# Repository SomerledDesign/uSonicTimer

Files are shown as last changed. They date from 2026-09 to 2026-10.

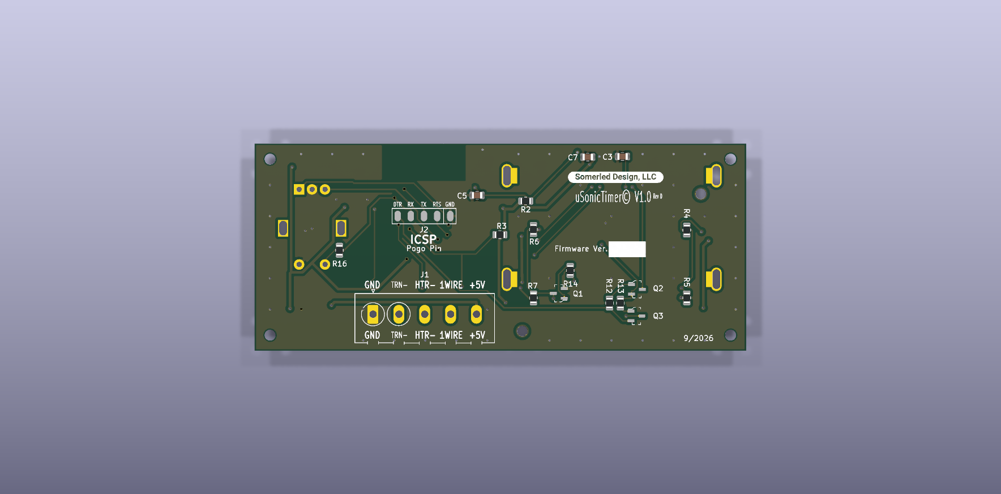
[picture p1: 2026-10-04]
hardware/uSonicTimer_1d/Renders/uSonicTimer1d_bottom.png

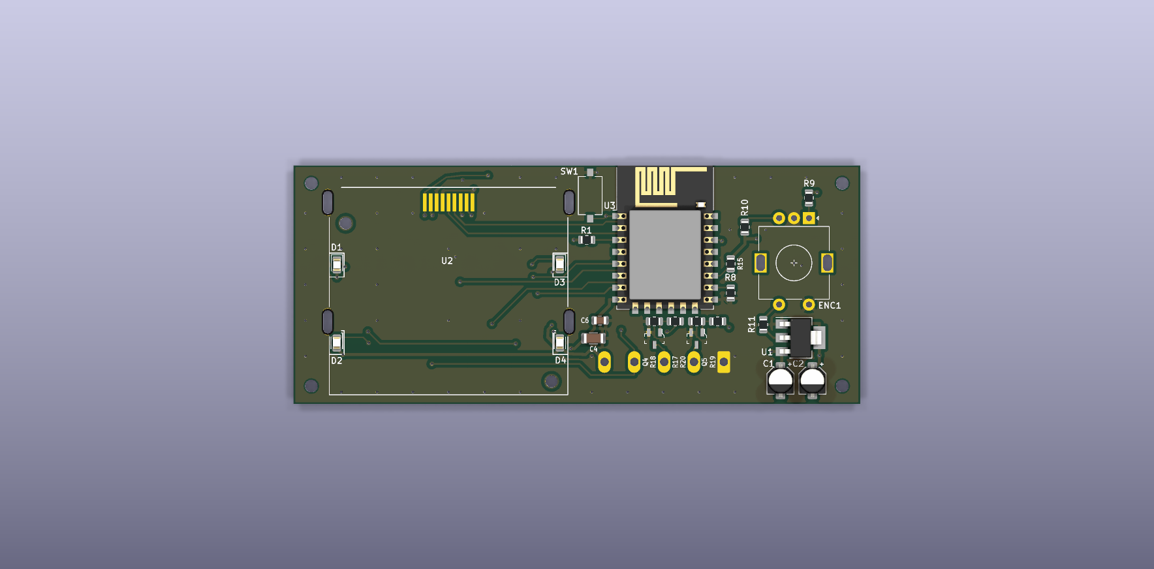
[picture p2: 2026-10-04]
hardware/uSonicTimer_1d/Renders/uSonicTimer1d_top.png

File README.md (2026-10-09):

# uSonicTimer

Firmware for a timer and heater controller I added to a cheap ultrasonic cleaner. It runs on an
**ESP8266 (ESP-12E module)**. A **Nokia 5110 (PCD8544, 84x48) LCD** shows a menu that you drive with a
**rotary encoder and its push button**. A **DS18B20 1-Wire temperature sensor** measures the bowl
temperature. Two outputs drive **solid-state relays** that switch the 110 VAC bowl **heater** and the
ultrasonic **cleaner**. The set temperature, timer preset, display unit (°F/°C), LCD contrast and
backlight brightness are saved in (emulated) EEPROM, so they survive a power cycle.

The menu approach comes from the [educ8s.tv](https://www.youtube.com/@Educ8s)
[menu tutorial](https://youtu.be/ak5TsUFhyf8?si=9JEMm8WbRyF4dVVC).

> Status: in active development (v0.6.1, PCB Rev D).

## What it does

1. On power-up it loads the settings from EEPROM. If a value is unset or out of range it uses a
   default: 72 °F, 10 min, °F, contrast 52 (raw 128), backlight level 10. It then initialises the
   LCD, the DS18B20, the encoder and the button.
2. It shows the main menu. You pick an item and a long press opens it.
3. **Start** runs the cleaner for the set time and regulates the heater (the control logic always
   works in °F, with tenths; the screens show whole degrees in the chosen unit):
   - **Heating:** below set − 10 °F the **heater is ON**, the **cleaner is OFF** and the countdown
     **holds**. The screen shows the bowl temperature in big digits and "Heating to 120°F"; the
     rule under the digits fills as the bowl warms from where heating started to set − 8 °F.
   - **Cleaning:** at set − 8 °F or above (2 °F hysteresis) the **heater is OFF**, the **cleaner is
     ON** and the countdown runs. The screen shows the time left as big `MM:SS` with a blinking
     colon, the rule under it fills with the run's progress, and "Now 118 Set 120°F" underneath.
     If the bowl drops below set − 10 °F the heater comes back on and the countdown holds again.
     Only cleaning time counts towards the run.
   - **No sensor:** heater locked off, cleaner on, the countdown runs; the time screen shows
     "NO SENSOR" instead of the temperatures.
   - When the time is up both outputs switch off and a big **DONE** stays on screen until you turn
     or press; then the menu returns. A long press during the run aborts it (both outputs off).

## Menu tree

In the menus, rotating the encoder moves the reverse-video highlight (lists show 4 rows under the
title bar and scroll; small arrows mark more items), a **long press** (> 1 s) enters the
highlighted item, and a **short press** toggles the LCD backlight between off and the level set in
**Set backlight**. The backlight is on at power-up.
Its state is kept while you are in a page, because short presses inside the pages move the cursor
or confirm instead. After 5 minutes without input in the menu the backlight dims to about 20 %; the
first turn or press then only wakes it. Every button press is handled exactly once, so a press never
carries over into the next page.

**Encoder test:** hold the button while powering up (or pressing reset) to get a test screen with the
live A/B levels, the detent count and how often each input has changed; long press returns to the
menu. Both edge counts should rise together while turning. `ENCODER_STEPS_PER_DETENT` in
`src/main.cpp` is 2 for an encoder whose detents rest at both 00 and 11, 4 for one that always rests
at the same state.

The backlight also shows the status (it swings between the set brightness and about 30 % of it, so
the screen stays readable):

- **Steady**: normal operation (menu, cleaning).
- **Flashing** (1 Hz): heating up.
- **Pulsing** (slow): the timer has finished; stops at the next turn or press.
- **Double-blink** every 2 s: no temperature sensor during a run (heater locked off, cleaner runs).

Pulsing and double-blink also show when the backlight has been toggled off or set to level 0 (then
at level 5); heating and cleaning then stay dark.

```
Main menu "uSonicTimer"      (shows the set temperature and time underneath)
├── Start             heating screen (big temperature) / timer screen (big MM:SS) / DONE, as above
│                     long press = abort (both outputs off)
└── Settings...
    ├── Set temp      "ddd°F" (3 digits) or "dd°C" (2 digits), cursor digit in reverse video
    │                 rotate = change digit (0–9, wraps); press = next digit ("Press = next"),
    │                 press on the last digit = save and return ("Press = save");
    │                 long press = save from any digit (clamped 60–180 °F / 16–82 °C, stored in °F)
    ├── Set time      "<n> min"; rotate = preset 3, 8, 10, 15, 20, 30, 60 min (wraps)
    │                 press = save and return
    ├── Set units     "°F Fahrenheit" / "°C Celsius"; rotate = toggle, press = save and return
    ├── Set backlight "Off" / "Level 1"…"Level 10" with a bar; rotate = level (previewed live)
    │                 press = save, switch the backlight on and return
    ├── Set contrast  20–100 with a bar (mapped onto the usable raw 80–200); clockwise = higher,
    │                 accelerated (detents < 40 ms apart = 5 steps, < 90 ms = 2, else 1),
    │                 applied live; press = save and return
    └── Exit          back to the main menu
```

Settings are saved to EEPROM when you leave their page: set temperature `0x00` (°F), time `0x08`,
contrast `0x10` (raw 80–200, so the 0.5.0 value carries over), backlight level `0x18`, units `0x20`
(0 = °F, 1 = °C) and a layout id `0x28` (0x60) that marks EEPROM written by 0.6.0 or later. Every
value is range-checked on load; a backlight level of 0 is only accepted together with that id.

## Hardware (PCB rev 1d) pin map

The KiCad design files for this board are in [`hardware/uSonicTimer_1d/`](hardware/uSonicTimer_1d/).

| Signal | Arduino pin | ESP8266 GPIO | ESP-12E pin | Notes |
|---|---|---|---|---|
| LCD SCLK | D5 | GPIO14 | 5 | software SPI clock |
| LCD DIN | D7 | GPIO13 | 7 | software SPI data |
| LCD D/C | D10 | GPIO1 (TX) | 22 | shared with UART TX |
| LCD CS | D4 | GPIO2 | 17 | 10K pull-up |
| LCD RST | – | – | – | not connected (`U8X8_PIN_NONE`) |
| LCD backlight | D8 | GPIO15 | 16 | via Q1, 10K pull-down |
| Encoder CLK (A) | D0 | GPIO16 | 4 | 4K7 pull-up (R9), polled (no interrupt on GPIO16) |
| Encoder DT (B) | D6 | GPIO12 | 6 | 4K7 pull-up (R10), polled |
| Encoder SW | D9 | GPIO3 (RX) | 21 | shared with UART RX |
| Heater SSR | D2 | GPIO4 | 19 | HIGH = ON |
| Cleaner SSR | D1 | GPIO5 | 20 | HIGH = ON |
| DS18B20 1-Wire | D3 | GPIO0 | 18 | 4K7 pull-up; also ~PROGRAM strap |

On rev 1d, NPN transistors switch the heater and cleaner SSRs low-side. The logic is the same as
before: GPIO HIGH = ON.

The programming header is a set of 5 pogo pads: 1 GND, 2 RTS, 3 TX, 4 RX, 5 DTR. RTS and DTR
drive the auto-reset/boot circuit (Q2/Q3).

Because the UART pins are also used for the LCD D/C line and the encoder switch, serial output
from the `debug` build shares those lines with the hardware.

## Building and flashing (PlatformIO)

The project uses the `espressif8266` platform, board `esp12e` and the Arduino framework. It needs
these libraries, which PlatformIO fetches automatically from `platformio.ini`:
`olikraus/U8g2`, `lennarthennigs/ESP Rotary`, `lennarthennigs/Button2`, `paulstoffregen/OneWire`
and `milesburton/DallasTemperature`. `EEPROM` and `Ticker` come with the ESP8266 core.

```sh
pio run -e release                  # build the release firmware
pio run -e release -t upload        # flash it over the programming header
pio device monitor -b 115200        # serial monitor (debug output)
```

- `release` is the default environment (`default_envs = release`); it builds without the debug
  output.
- `debug` (`pio run -e debug`) adds `-Og -ggdb -g3 -D DEBUG -D WITH_GDB`. It enables the
  serial `debug()`/`debugln()` output at 115200 baud.
- `platformio.ini` puts `build_dir` and `libdeps_dir` under
  `$HOME/Library/Caches/PlatformIO/uSonicTimer/`, which keeps build output out of Dropbox. On a
  non-macOS machine, change these paths or remove them to use the default `.pio/` folder.

## Versioning

Firmware versions are a semantic version plus a build number, shown as **`0.6.1 (73)`** (current).

- Bump PATCH for fixes and MINOR for features; 1.0.0 is the first version installed and in service.
- The build number goes up by 1 for every build flashed for testing and never resets.
- `FW_VERSION`, `FW_BUILD` and `HW_REV` at the top of `src/main.cpp` set it. The startup screen
  shows `uSonicTimer` / `v0.6.1 (73)` / `PCB Rev D` for 1.5 s at power-up. Releases are tagged
  `vMAJOR.MINOR.PATCH` in git.

History:

- **0.6.1 (73)**: new big-digit font: blocky, squared-off 7-segment-style characters (4–5 px
  strokes, no diagonals, stepped slashed zero, colon of two 4x4 blocks) drawn from box lists in
  `include/bigfont.h`, closer to the reference clock than the scaled 5x7 font. Encoder
  acceleration in Set contrast (5 / 2 / 1 steps per detent for detents
  < 40 ms / < 90 ms / slower apart). A press saves in every settings page ("Press = save"); in Set
  temp a press moves to the next digit and saves on the last one, long press still saves anywhere.
  Detents still queued when a page closes no longer move the menu highlight.
- 0.6.0 (72): big-digit run screens in the style of a Nokia 5110 clock (Adafruit 5x7 digits
  scaled to 15x28 px, a rule that doubles as a progress bar, one line of small text): heating
  screen with the bowl temperature, timer screen with blinking colon, DONE screen. The countdown
  holds while heating (heater below set − 10 °F, cleaning resumes at set − 8 °F). Main menu is now
  Start / Settings...; Settings has Set temp, Set time, Set units (°F/°C, new), Set backlight
  (0 = off, new), Set contrast (shown as 20–100) and Exit, with title bars.
- 0.5.0 (71), `2d4bacc`: version defines, startup screen, versioning notes.
- Build 70, `a255348`: polled quadrature decoder (replaces ESPRotary) and the encoder test screen.
- Build 69, `44c0249`: backlight as status indicator and the Backlight brightness menu (`90cbc71`).

## Setup and usage

1. Wire the board as in the pin map, or use the rev 1d PCB. Put the DS18B20 on the bowl and
   connect the heater and cleaner through the SSRs.
2. Build and flash as above, then power up. The main menu appears.
3. Open **Settings...** and use **Set temp** to choose the target bowl temperature, **Set time**
   to choose the run time, **Set units** for °F or °C, and **Set backlight** / **Set contrast** for
   the LCD if needed. Each setting is saved when you leave its page.
4. Highlight **Start** and long-press. The display shows the bowl temperature while it heats, then
   the time left while it cleans; the heater and cleaner are controlled automatically.
5. Long-press at any time to stop. Both outputs switch off. When the time is up, DONE shows until
   you turn or press.

## Repository layout

- `src/main.cpp`: the firmware (setup, menus, pages, run control, EEPROM, backlight).
- `src/screens.cpp`, `include/screens.h`: drawing for the run screens, menus and settings pages.
- `include/ust_logic.h`: run-control hysteresis, °F/°C, contrast and progress helpers (no Arduino
  dependencies).
- `include/bigfont.h`: the big-digit font (blocky 15x28 characters as box lists, slashed zero).
- `tools/host/`: host-side test of `ust_logic.h` and a screen preview that runs the real drawing
  code against the U8g2 C library on a PC (`tools/host/build.sh`, writes PNGs to
  `tools/host/out/`).
- `src/sketch.md`: design notes and the original specification.
- `include/`: also the old splash/footer glyph bitmaps.
- `handoff.md`: latest status and decisions.
- `hardware/uSonicTimer_1d/`: KiCad project for the rev 1d controller board (schematic, PCB,
  project symbol/footprint libraries, Gerbers, interactive BOM and renders).
- `extras/` (git-ignored): local reference material. This includes third-party menu/encoder demo
  code, links to the KiCad hardware projects and links to the datasheets, which are archived
  centrally.

## License

uSonicTimer uses two licences, one for the code and one for the hardware:

- **Firmware and code** (`src/`, `include/`, `platformio.ini` and the rest of the software) are
  under the GNU General Public License, version 3 or later. See [`LICENSE`](LICENSE).
  SPDX-License-Identifier: GPL-3.0-or-later
- **Hardware design files** (everything under [`hardware/`](hardware/): the KiCad schematic,
  PCB, libraries and related fabrication files for the controller board, and the same files
  wherever else they are published for this project) are under the CERN Open Hardware Licence
  Version 2, Strongly Reciprocal. See [`LICENSE-HARDWARE`](LICENSE-HARDWARE).
  SPDX-License-Identifier: CERN-OHL-S-2.0

Both licences come with no warranty. This controller switches 110 VAC mains through solid-state
relays; build and use it at your own risk.

Copyright © 2024 Somerled Design, LLC.

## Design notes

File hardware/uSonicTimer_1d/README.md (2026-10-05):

# uSonicTimer controller board, rev 1d

KiCad 10 project for the uSonicTimer controller PCB (schematic rev D). The firmware
pin map in the top-level [`README`](../../README.md) matches this board.

| Path | Contents |
|---|---|
| `uSonicTimer1d.kicad_pro` | KiCad project (open this) |
| `uSonicTimer1d.kicad_sch` | Schematic |
| `uSonicTimer1d.kicad_pcb` | PCB layout |
| `uSonicTimer1d.kicad_dru` | Custom design rules |
| `uSonicTimer1d.kicad_sym`, `sym-lib-table` | Project symbol library |
| `uSonicTimer1d.pretty/`, `fp-lib-table` | Project footprint library |
| `3dmodels/` | Project 3D models folder (currently only a README: sources, licences and excluded models) |
| `Gerber/` | Fabrication outputs: Gerbers, drill files, job file and `uSonicTimer1d_revD_gerbers.zip` for ordering |
| `bom/ibom.html` | Interactive BOM (open in a browser) |
| `Renders/` | Top and bottom board renders |
| `[TODO]/` | Changes planned for the next board revision |

The library tables use `${KIPRJMOD}`, so the project opens from any location. Every
symbol and footprint is in the project libraries. Every 3D model comes from the stock
KiCad 10 3D library, so nothing is needed outside this folder and a standard KiCad 10
install. The encoder (ENC1) and the screw terminal (J1) have no 3D body: their
third-party models can't be redistributed. Sources and licences are listed in
[`3dmodels/README.md`](3dmodels/README.md).

Licensed under the CERN Open Hardware Licence Version 2, Strongly Reciprocal. See
[`LICENSE-HARDWARE`](../../LICENSE-HARDWARE).
SPDX-License-Identifier: CERN-OHL-S-2.0

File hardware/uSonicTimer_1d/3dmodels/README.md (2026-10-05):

# 3D models: uSonicTimer rev 1d

This folder holds the project-local 3D models. Footprints reference them as
`${KIPRJMOD}/3dmodels/<file>.step`. The other bodies on the board (resistors,
capacitors, LEDs, Q1-Q5, SW1, U1, U3 and so on) come from the stock KiCad 10 3D library
(`${KICAD10_3DMODEL_DIR}`, installed with KiCad). That library is licensed under CC-BY-SA 4.0
with the KiCad library exception, so it can be used in any design.

## Our own models (in this folder)

Drawn by Somerled Design (Kevin Murphy) with Mildrew (Grok Bot).
Licence: CERN-OHL-S-2.0 (same as the rest of this hardware; see `LICENSE-HARDWARE` in the repository root).

Each model comes as a multi-colour STEP (one coloured solid per part) and a coloured VRML
(`.wrl`, KiCad scale 1 unit = 2.54 mm). Both are generated by `build_3dmodels.py` in this folder (CadQuery; run `python build_3dmodels.py`), which is the editable source. The model origin is
the footprint origin, so every footprint uses offset 0 0 0, scale 1 and rotation 0 0 0.
Dimensions are taken from the datasheets listed. Where a datasheet gives no value, the table
says what was used instead.

| File | Used by | Datasheet (dimension source) |
|---|---|---|
| `RotaryEncoder_Alps_EC11E_Switch_Vertical_H20mm.step` / `.wrl` | ENC1, footprint `RotaryEncoder_Alps_EC11E-Switch_Vertical_H20mm` | Alps Alpine EC11E series catalogue, Drawing No.2/No.3 (with push switch): https://tech.alpsalpine.com/cms.media/product_catalog_ec_01_ec11e_en_611f078659.pdf |
| `TerminalBlock_Metaltex_BR4_1x05_P5.00mm_Horizontal.step` / `.wrl` | J1, footprint `ScrewContact_ALLELEC_2,5_5-G-5,00_1x05_P5.00mm_Horizontal_copy_copy` | Metaltex BR4 terminal block (BR402V + BR403V, 5.0 mm pitch): https://metaltex.com.br/cdn/shop/files/br4.pdf |
| `LCD_Nokia_5110-3310_bare_frame.step` / `.wrl` | U2, footprint `Nokia_5110-3310_LCD_uSonic1d` | Goldentek GG0804A1FSN6G (PCD8544 84x48 glass) spec, section 12 "Outline dimension": https://thecustomizewindows.cachefly.net/wp-content/uploads/2017/06/Nokia-5110-datasheet.pdf, plus Kevin's frame measurements (`measurements.md`, `extras/bezel/README_bezel.md`) |

### ENC1: Alps EC11E with push switch, vertical, 20 mm shaft

From the datasheet:
- Body 12 x 11.7 mm. Shaft axis 7.5 mm from pins A/C/B and 7 mm from switch pins D/E.
  A-C-B pitch 2.5 mm, D-E 5 mm.
- Mounting surface 4.5 mm above the PCB. Overall height 24.5 mm (20 mm from the mounting surface).
- Bushing length 7 mm.
- Shaft Ø6 mm, flat 4.5 mm across over the top 10 mm.
- Pins and mounting tabs 3.5 mm below the PCB.

Not given in the datasheet, so assumed:
- Bushing Ø7 mm.
- Split between the black housing (0-3.8 mm) and the silver metal frame (2.0-4.5 mm).
- Pin cross-section 0.3 x 0.8 mm and tab size 2.0 x 0.5 mm.
- Tip chamfer 0.5 mm (the drawing says C1).
- Direction of the shaft flat.

The mounting tabs are drawn at the footprint's MP pads, which are 11.2 mm apart. The datasheet
hole pattern gives 12.5 ±0.05 mm.

### J1: 5-way 5.0 mm terminal block (Metaltex BR4)

From the datasheet:
- 5.0 mm per way; body 25 mm long (2.5 mm overhang past the end pins).
- 10.2 mm deep. Pin 5 mm from the wire-entry face, which faces the footprint's +Y side, where
  the silkscreen entry marks are.
- 14.2 mm high. Pins 0.8 mm square, 3.5 mm long.
- M2.5 zinc-plated screws; green PA66 housing.
- Drawn as one 2-way plus one 3-way block (BR402V + BR403V), with the joint between pins 2 and 3.

Not dimensioned in the drawing, so read off it:
- Shoulder height 9 mm and top width about 6.2 mm.
- Wire-entry opening 3.2 x 5.8 mm.
- Screw head Ø4 mm, recessed 1.8 mm.

The 0.6 mm interlock step is not modelled.

The board previously used Metaltex `BR1102V` + `BR1103V` models scaled by 0.5. The BR11 series
(https://metaltex.com.br/cdn/shop/files/br11.pdf) has a **9.5 mm** pitch, so it does not fit this
5.00 mm footprint. BR4 is Metaltex's 5.0 mm modular equivalent. The footprint's own fab outline
is a generic 27 x 9.5 mm box, so the model is 1 mm deeper at the back than that outline.

### U2: bare Nokia 5110/3310 LCD in its metal frame

The footprint is for the bare LCD with its metal frame (elastomer contacts on 9 SMD pads, four
frame tabs in slots, backlight LEDs D1-D4 on this board), not for the red/blue breakout board.
So the model has no breakout PCB or header.

From the datasheet:
- Glass 38.36 x 33 mm, with a 6.4 mm contact ledge (upper plate 26.6 mm).
- Glass stack 2.0 mm thick (maximum).
- Viewing area 34.96 x 23.4 mm, 1.7 mm from the glass edges.

From Kevin's measurements:
- Frame opening 36.23 x 25.85 mm.
- Frame borders: 1.6 mm left and right, 6.77 mm on the contact side, 1.45 mm on the other side.
- So the frame outline is 39.43 x 34.07 mm. Its contact-side edge is on the footprint's y = 0
  silk line, as in the bezel notes.

Assumed or taken from the footprint:
- Frame top 4.4 mm above the PCB. This is the 6 mm module thickness (Hobby Components spec)
  minus the breakout PCB; no datasheet gives it.
- Light guide 2.1 mm, with LED pockets at the silkscreen notches.
- Locating pegs in the two Ø2 mm holes.
- Tabs 0.4 x 2.8 mm at the slot centres.
- Elastomer strip 10 x 3 mm.

## Third-party models removed from the board and the project footprints (2026-10-04)

| Part | Footprint | Model referenced before | Source and licence | Decision |
|---|---|---|---|---|
| Q1-Q5 | `SOT-23-3` | `/Users/.../KiCad/lib/3dmodels/km3dpacks/User Library-SOT23-3.step` (absolute path) | Downloaded by Kevin from Dassault's 3D ContentCentral (3dcontentcentral.com); the "User Library-…" name is its export naming. SolidWorks 2022 STEP, 2023-02-13. User-uploaded under Dassault's terms. | **Not committed** (no redistribution licence). Replaced by the stock `Package_TO_SOT_SMD.3dshapes/SOT-23-3.step` (same package, same pad layout). |
| ENC1 | `RotaryEncoder_Alps_EC11E-Switch_Vertical_H20mm` | `${MYSPECLMOD}/EC11 Rotary Encoder Dode Switch-15mm .STEP` (offset 7.5 -2.5 0.1, rot 0 0 90) | GrabCAD model "EC11 Rotary Encoder Dode Switch-15mm" by user *xindela* (SolidWorks 2016, 2021-10-20). GrabCAD terms allow only non-commercial, internal use, under a non-sublicensable licence. | **Not committed** (can't be relicensed or redistributed). Replaced by our own `RotaryEncoder_Alps_EC11E_Switch_Vertical_H20mm.step` (see above). |
| ENC1 (hidden) | same | `${MYSPECLMOD}/User Library-EC11B15244.STEP` | Downloaded by Kevin from 3D ContentCentral ("User Library-…" export naming). User-uploaded under Dassault's terms. File is no longer on Kevin's machines. | Removed |
| ENC1 (hidden) | same | `${KICAD6_3DMODEL_DIR}/Rotary_Encoder.3dshapes/...EC11E-Switch_Vertical_H20mm.wrl` | KiCad stock path, but KiCad 10 ships no such model. | Removed (dangling) |
| SW1 | `SW_Tactile_SPST_NO_Straight_CK_PTS636Sx25SMTRLFS` | `${MYSPECLMOD}/g73-6x3-5-mm-smd-button-1/...PTS636Sx25SMTRLFS.STEP` | File isn't on Kevin's machines. Probably 3D ContentCentral like the others; the folder name also looks like a GrabCAD download ("g73-6x3-5-mm-smd-button-1"). | Removed. The stock KiCad model for this exact C&K part was already on the footprint (hidden); it is now shown. |
| J1 | `ScrewContact_ALLELEC_2,5_5-G-5,00_1x05_P5.00mm_Horizontal_copy_copy` | `${MYSPECLMOD}/pcb-terminal-blocks-1/BR1102V.stp` and `BR1103V.stp` (scaled 0.5) | Files aren't on Kevin's machines. Probably 3D ContentCentral like the others; the folder name also looks like a GrabCAD download ("pcb-terminal-blocks-1"). | Removed. Replaced by our own `TerminalBlock_Metaltex_BR4_1x05_P5.00mm_Horizontal.step` (see above). |
| U2 | `Nokia_5110-3310_LCD_uSonic1d` | none | n/a | Our own `LCD_Nokia_5110-3310_bare_frame.step` added (see above). |

### Where the excluded models came from

Kevin downloaded most of the excluded models from **3D ContentCentral**
(3dcontentcentral.com, run by Dassault Systèmes; the site appears to be gone now):
- Q1-Q5 `User Library-SOT23-3`
- ENC1 `User Library-EC11B15244`
- probably the SW1 and J1 models too

The `User Library-…` file names match 3D ContentCentral's export naming. These models
were uploaded by users under Dassault's terms, which give no licence to redistribute
them, so they are not included in this CERN-OHL-S repository. Keep them in a local
library instead. The EC11 encoder model (`EC11 Rotary Encoder Dode Switch-15mm`) is
attributed to GrabCAD user *xindela*, as above.

`${MYSPECLMOD}` is not defined in Kevin's KiCad 9/10 configuration. So none of the
`MYSPECLMOD` models resolved on any machine before this change either.

To see the original third-party bodies locally, Kevin can add them back in his own copy, but
must not commit them. Use `${KIPRJMOD}/3dmodels/<file>`, add the file names to a local
`.git/info/exclude`, and use the offsets listed above.

## Symbol and footprint libraries (project-local, `${KIPRJMOD}`)

| Library | Contents | Sources and licences |
|---|---|---|
| `uSonicTimer1d.kicad_sym` (`sym-lib-table`, nickname `uSonicTimer1d`) | All 19 symbols the schematic uses | KiCad stock symbols, CC-BY-SA 4.0 with the KiCad library exception. `EOMZ-240D25R` and `MMBT3904LT1G` come from the Digi-Key KiCad Library, CC-BY-SA 4.0 with a design-use exception (https://github.com/Digi-Key/digikey-kicad-library). `Nokia_5110_LCD` is Kevin's own (km-kicad-library). |
| `uSonicTimer1d.pretty` (`fp-lib-table`, nickname `uSonicTimer1d`) | All 17 footprints on the board | Mostly KiCad stock footprints, CC-BY-SA 4.0 with the exception. `SOT-23-3` is the Digi-Key KiCad Library version, CC-BY-SA 4.0 with the exception. `ICSP_5_POGO`, `Nokia_5110-3310_LCD_uSonic1d` and `kibuzzard-63EC72D8` (KiBuzzard silkscreen label) are Kevin's own. `ScrewContact_ALLELEC_...` comes from Kevin's personal `Connector_ScrewTerminal.pretty`; it follows the KiCad terminal-block generator format and its origin isn't otherwise documented. |

Only the stock KiCad libraries (for example `Package_TO_SOT_THT`, used in the DS18B20
footprint field) and the stock 3D library are taken from the KiCad installation.

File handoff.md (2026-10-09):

## Handoff

1. Latest request: 0.6.1 (73), a follow-up (acceleration, Press = save) to the 0.6.0 (72) UI
   milestone: big-digit run screens (heating / timer / DONE), countdown holds while heating with
   2 °F hysteresis, Settings... submenu, °F/°C units, backlight 0 = off, contrast shown as 20-100.
2. Current status: built (release and debug) and committed locally with tags `v0.6.0` and
   `v0.6.1`; not flashed or pushed yet. Screen previews: `tools/host/build.sh` (renders the real drawing code to PNGs).
3. Decisions:
   - Network/WiFi features are not needed for this project.
   - `release` is the default PlatformIO environment.
   - Heater on below set - 10 °F; cleaning and countdown resume at set - 8 °F. A run that starts
     within 10 °F of the set temperature starts cleaning straight away (as before).
   - Set time keeps the presets 3, 8, 10, 15, 20, 30, 60 min.
   - Backlight level 0 = off; the done pulse / fault blink then use level 5.
   - 0.6.1 (73): blocky big-digit font (box lists in include/bigfont.h) modelled on the
     cbm80amiga clock. "Press = save" in every settings page (Set temp: press = next digit, saves on
     the last digit; long press saves anywhere). Encoder acceleration only in Set contrast.
4. Open questions: flash and check the screens, the contrast mapping and the acceleration feel
   on the real hardware. Set time keeps its presets (decided).

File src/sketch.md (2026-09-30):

## Define the Project

- What is the Project?

- Which features are nice to have?

## Create Workflow

Create a workflow with [github](https://www.github.com) or [trello](https://www.trello.com)...

## task breakdown

1.  Display splash screen
2.  Load from EEPROM
3.  Display Menu
4.  Wait for input
5.  Display input page
5.1 Redraw menu with input

## Original specification

The specification below (formerly `src/uSonicTimerspecifications.txt`) was submitted to ChatGPT
to generate the first version of the firmware. It is kept here verbatim for reference; the
current firmware in `main.cpp` is the source of truth where the two differ.

```text
Please write a C++ Arduino program for an ESP8266.  The program is a menu driven countdown timer to control a bowl heater and operation of an Ultrasonic Cleaner. A NOKIA 5110 display is used for the GUI menu system and can set the presets, set the desired temperature, start the countdown, adjust the LCD contrast, etc.
Included libraries are: "OneWire", "DallasTemperature", "ESPRotary", "Button2", "U8g2lib" and any other ones which you deem necessary.
In setup() the currentTemperature variable should be set to read the temperature of the DS18B20. The setTemperature and setTimer variables should be initialized to their defaults or last settings if available.
There should be 4 menu items on the main menu page: 
    1.) Start Timer
    2.) Set Timer
    3.) Set Temperature
    4.) Contrast
Each main menu page can be select by rotating an encoder and the menuItem becomes highlighted with reverse video (white letters on black background) if the encoder button is then long pressed the submenu page for that item is shown.
If the Start Timer menuItem is selected and there is a long press this will bring up an über page with just the timer (counting down) and the current and set temperature of the DS18B20. The program will then turn on the heater (if the tempSetting is greater than the currentTemperature).  When the currentTemperature is within the tempOffset value (usually 10 degrees Fahrenheit) lower than tempSetting the heater can be turned off and the cleaner can be turned on.  Both the heater and the cleaner are controlled by solid state relays switching the required 110VAC supply.
Submenu pages for Set Timer, Set Temperature and Contrast are used to set a preset time (3 min, 8 min, 10 min, 15 min, 20 min, 30 min and 60 min); adjust set temperature; and adjust the LCD contrast respectively.
Both the 'Set Temperature' and 'Contrast' submenus utilize a selectable cursor (Selecting cursor by clicking [short press] the shaft button of the encoder).  Repeated clicking changes the unit to which the cursor is set.  From units to tens, to hundreds (if used) and then back to units; The cursor is indicated by a reverse video digit. Turning the encoder shaft to the left or the right would then 'decrease' or 'increase' the digit under the cursor respectively.
The Set Timer submenu displays the preset times, one at a time, and turning the encoder shaft left or right scrolls through the preset times, wrapping around when the end or beginning of the list is reached. The timer submenu will set the timer value.
Menu display routine should minimize artifacts (left over pixels from previous displays).
```

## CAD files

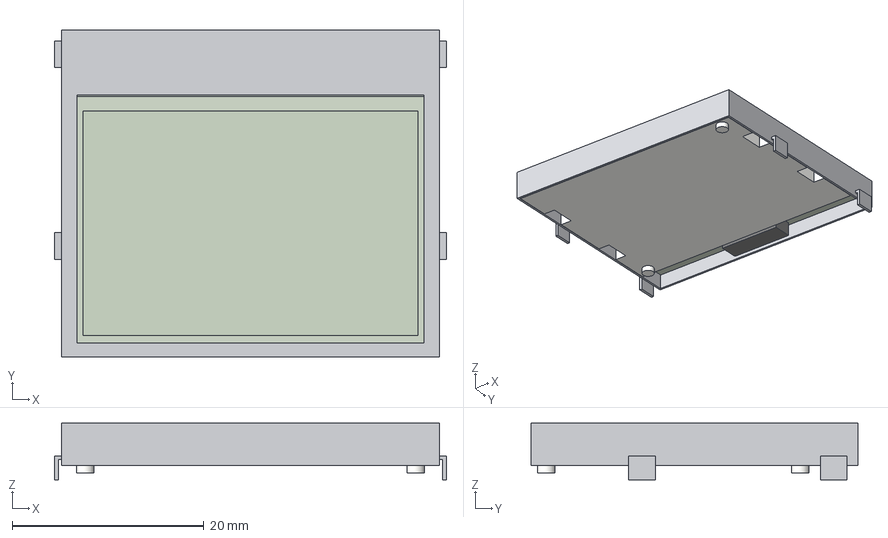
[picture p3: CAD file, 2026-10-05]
hardware/uSonicTimer_1d/3dmodels/LCD_Nokia_5110-3310_bare_frame.step
40.9 x 34.1 x 5.90 mm
frame
lightguide
elastomer
glass_lower
glass_upper
viewing_area

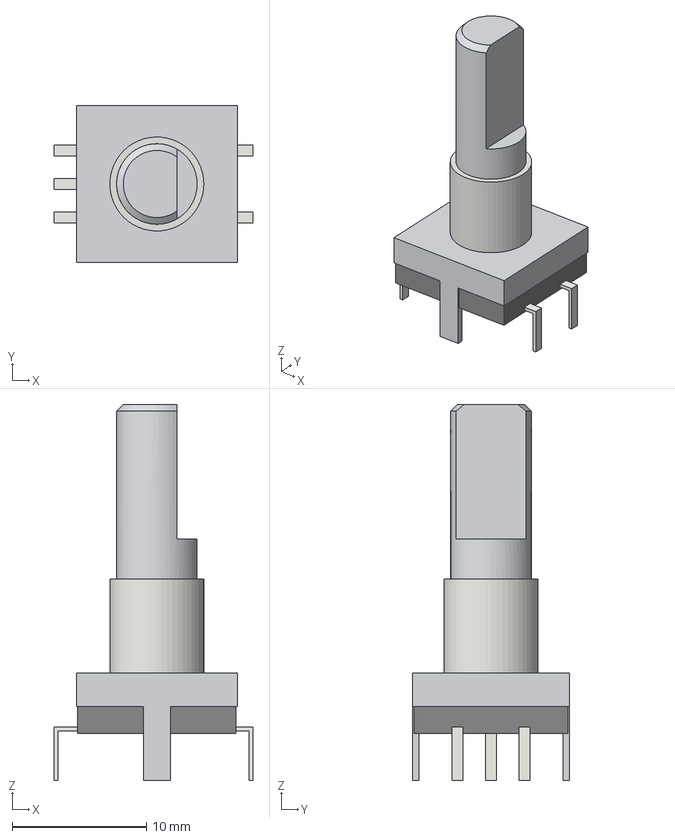
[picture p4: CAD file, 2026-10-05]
hardware/uSonicTimer_1d/3dmodels/RotaryEncoder_Alps_EC11E_Switch_Vertical_H20mm.step
14.8 x 11.7 x 28.0 mm
housing
frame
bushing
shaft
pins

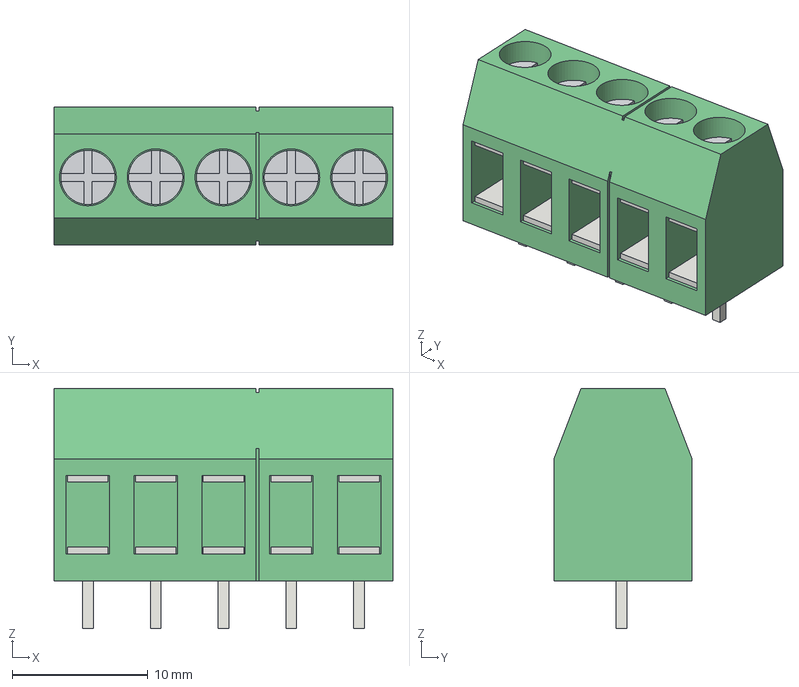
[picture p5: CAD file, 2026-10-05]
hardware/uSonicTimer_1d/3dmodels/TerminalBlock_Metaltex_BR4_1x05_P5.00mm_Horizontal.step
25.0 x 10.2 x 17.7 mm
housing
screws
clamps
pins

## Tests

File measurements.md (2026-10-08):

--- Measurements of the whole hole ---

    1. the actual ragged hole: left, right, top and bottom edges, measured from the panel's left and bottom edges;
        -- Left to Right edge bottom: 40.06 mm
        -- Left to Right edge top: 40.00 mm  
        -- Top to Bottom left: 28.17 mm  
        -- Top to Bottom right: 28.55 mm  
    2. distance from the bottom left board mount hole to left edge of display hole
        -- 2.31 mm
    3. the front panel's thickness;
        -- 3.36 mm
    4. the visible area of the 5110 glass and how far in it sits from the module edges;
        The glass is under a metal bezel.  Edges of the bezel.
        -- Thickness of the metal border left: 1.6 mm
        -- Thickness of the metal border right: 1.6 mm
        -- Thickness of the metal border top: 6.77 mm
        -- Thickness of the metal border bottom: 1.45 mm
        I don't know the actual display area, but I remember it was pretty far in all around.

        The display sits behind the cutout as follows: 
        start of glass after border:
        - glass is 1.16 mm lower than the top edge
        - glass is 1.16 mm above the bottom edge
        - glass is 2.61 mm right of the left edge
        - glass is 1.16 mm left of the right edge
    5. how far the glass sits behind the front face.
        - glass is 6.01 mm behind front of panel

    picture of panel: ../Penus/images/

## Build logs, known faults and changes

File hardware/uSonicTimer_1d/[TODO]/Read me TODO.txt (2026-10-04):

Changes to implement in the next version/issue of the board.

SCHEMATIC:
Separate GPIO0 and CLK from rotary encoder.  This might not work as it pulls GPIO0 low during operation of the encoder, thereby putting the esp12e into Bootloader mode. :^(
Make ICSB connector 3x2 header.  Put guard box around connector (POGO pins seem to work alright so skip this)

When using HW SPI use all the pins. 
So CS/SS should be used as the 5110 might require it for sync with the master.
USE Hardware SPI on NOKIA 5110 as follows:
Change DT (data encoder) from GPIO12 (MISO) to GPIO15.  This is held low by a 10K resistor (for boot purposes) so connect the 

BLOCK DIAGRAM:

PCB:
The pcb material should be 0.8mm, not the standard 1.6mm
Adjust for Surface mounted 6 pin ICSB connector.
Make KeepOut bigger by 5mm per side of the antenna

PRODUCTION:

FIRMWARE:

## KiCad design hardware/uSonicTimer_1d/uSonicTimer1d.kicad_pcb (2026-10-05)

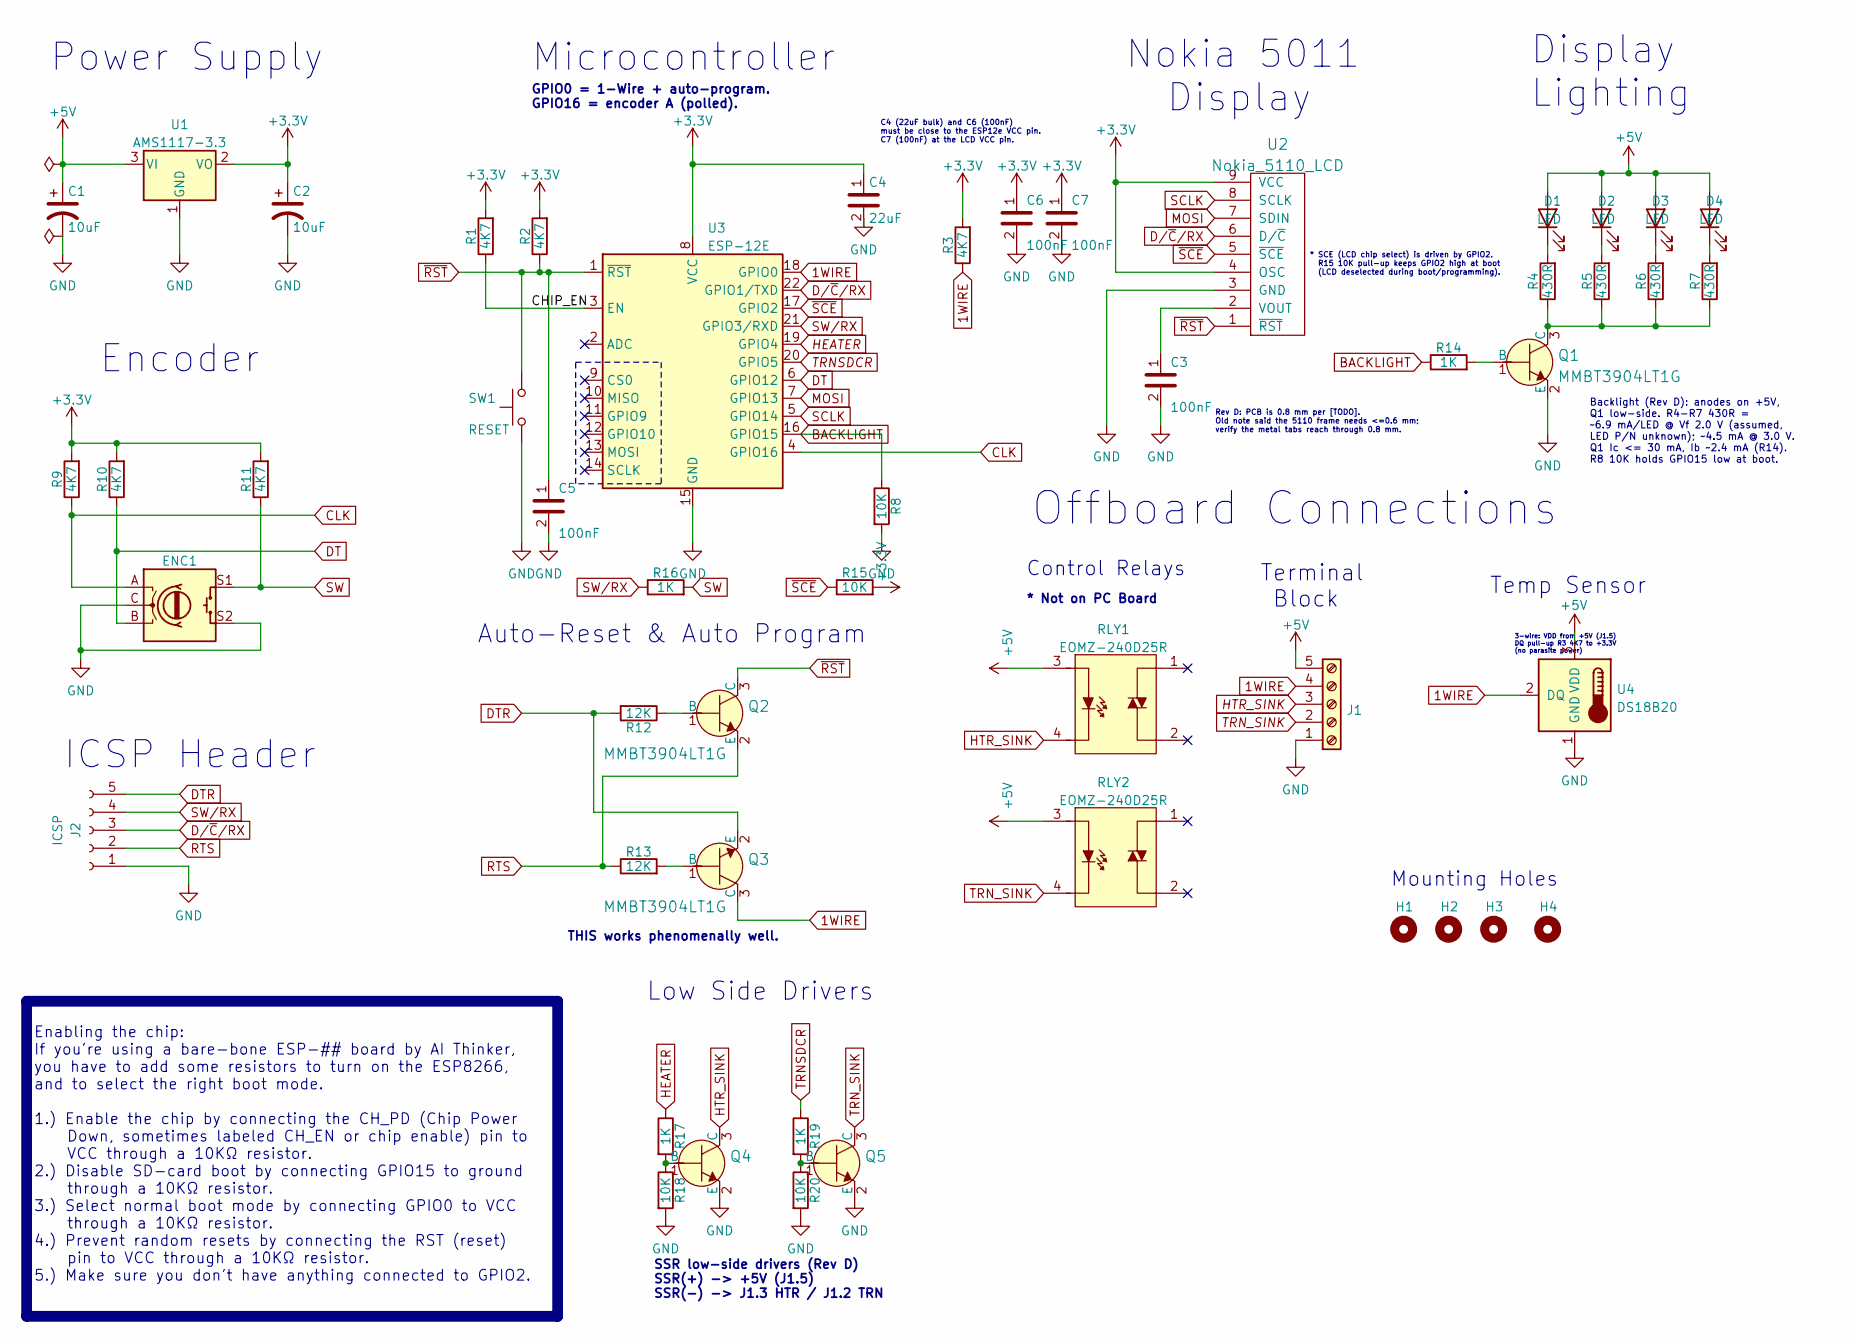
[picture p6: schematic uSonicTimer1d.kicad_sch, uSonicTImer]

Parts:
C1, C2: 10uF; CP_Elec_4x5.4; MPN UWT1C100MCL1GB; Digikey PN 493-2173-1-ND
C3, C5, C6, C7: 100nF; C_0805_2012Metric; MPN 08055C104KAT4A; Digikey PN 478-10836-1-ND
C4: 22uF; C_1206_3216Metric
D1, D3: LED; LED_0805_2012Metric
D2: LED; LED_0805_2012Metric_SilkTrim_D2
D4: LED; LED_0805_2012Metric_SilkTrim_D4
ENC1: RotaryEncoder_Switch; RotaryEncoder_Alps_EC11E-Switch_Vertical_H20mm
H1, H2, H3, H4: MountingHole; MountingHole_2.1mm
J1: Screw_Terminal_01x05; ScrewContact_ALLELEC_2,5_5-G-5,00_1x05_P5.00mm_Horizontal_c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
J2: ICSP; ICSP_5_POGO
Q1, Q2, Q3, Q4, Q5: MMBT3904LT1G; SOT-23-3; MPN MMBT3904LT1G; Digi-Key_PN MMBT3904LT1GOSCT-ND
R1, R2, R3, R9, R10, R11: 4K7; R_0805_2012Metric; MPN CRGCQ0805J4K7; Digikey PN A130138CT-ND
R4, R5, R6, R7: 430R; R_0805_2012Metric
R8, R15, R18, R20: 10K; R_0805_2012Metric; MPN CRGCQ0805J10K; Digikey PN A130140CT-ND
R12, R13: 12K; R_0805_2012Metric; MPN CRG0805F12K; Digikey PN A126337CT-ND
R14, R16, R17, R19: 1K; R_0805_2012Metric
RLY1, RLY2: EOMZ-240D25R; MPN EOMZ-240D25R; Digi-Key_PN SSR-240D25R
SW1: RESET; SW_Tactile_SPST_NO_Straight_CK_PTS636Sx25SMTRLFS
U1: AMS1117-3.3; SOT-223-3_TabPin2
U2: Nokia_5110_LCD; Nokia_5110-3310_LCD_uSonic1d
U3: ESP-12E
U4: DS18B20; TO-92_Inline

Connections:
1WIRE: J1.4, Q3.3 (C), R3.1, U3.18 (GPIO0), U4.2 (DQ)
+3.3V: C2.1, C4.1, C6.1, C7.1, R1.2, R2.2, R3.2, R9.2, R10.2, R11.2, R15.2, U1.2 (VO), U2.4 (OSC), U2.9 (VCC), U3.8 (VCC)
+5V: C1.1, D1.2 (A), D2.2 (A), D3.2 (A), D4.2 (A), J1.5, RLY1.3 (A), RLY2.3 (A), U1.3 (VI), U4.3 (VDD)
/CHIP_EN: R1.1, U3.3 (EN)
BACKLIGHT: R8.1, R14.1, U3.16 (GPIO15)
CLK: ENC1.A, R9.1, U3.4 (GPIO16)
DT: ENC1.B, R10.1, U3.6 (GPIO12)
DTR: J2.5, Q3.2 (E), R12.2
D/~C/RX: J2.3, U2.6 (D/~C), U3.22 (GPIO1/TXD)
GND: C1.2, C2.2, C3.2, C4.2, C5.2, C6.2, C7.2, ENC1.C, ENC1.S2, J1.1, J2.1, Q1.2 (E), Q4.2 (E), Q5.2 (E), R8.2, R18.2, R20.2, SW1.1, U1.1 (GND), U2.3 (GND), U3.15 (GND), U4.1 (GND)
HEATER: R17.1, U3.19 (GPIO4)
HTR_SINK: J1.3, Q4.3 (C), RLY1.4 (K)
MOSI: U2.7 (SDIN), U3.7 (GPIO13)
unnamed: D1.1 (K), R4.2
unnamed: D2.1 (K), R5.2
unnamed: D3.1 (K), R6.2
unnamed: D4.1 (K), R7.2
unnamed: Q1.1 (B), R14.2
unnamed: Q1.3 (C), R4.1, R5.1, R6.1, R7.1
unnamed: Q2.1 (B), R12.1
unnamed: Q3.1 (B), R13.2
unnamed: Q4.1 (B), R17.2, R18.1
unnamed: Q5.1 (B), R19.2, R20.1
unnamed: C3.1, U2.2 (VOUT)
RTS: J2.2, Q2.2 (E), R13.1
SCLK: U2.8 (SCLK), U3.5 (GPIO14)
SW: ENC1.S1, R11.1, R16.2
SW/RX: J2.4, R16.1, U3.21 (GPIO3/RXD)
TRNSDCR: R19.1, U3.20 (GPIO5)
TRN_SINK: J1.2, Q5.3 (C), RLY2.4 (K)
~RST: C5.1, Q2.3 (C), R2.1, SW1.2, U2.1 (~RST), U3.1 (~RST)
~SCE: R15.1, U2.5 (~SCE), U3.17 (GPIO2)

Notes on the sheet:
Auto-Reset & Auto Program
Terminal Block
SSR low-side drivers (Rev D) SSR(+) -> +5V (J1.5) SSR(-) -> J1.3 HTR / J1.2 TRN
Low Side Drivers
Control Relays
Mounting Holes
* SCE (LCD chip select) is driven by GPIO2. R15 10K pull-up keeps GPIO2 high at boot (LCD deselected during boot/programming).
Offboard Connections
Nokia 5011 Display
* Not on PC Board
GPIO0 = 1-Wire + auto-program. GPIO16 = encoder A (polled).
Microcontroller
Rev D: PCB is 0.8 mm per [TODO]. Old note said the 5110 frame needs <=0.6 mm; verify the metal tabs reach through 0.8 mm.
Display Lighting
ICSP Header
C4 (22uF bulk) and C6 (100nF) must be close to the ESP12e VCC pin. C7 (100nF) at the LCD VCC pin.
Temp Sensor
3-wire: VDD from +5V (J1.5) DQ pull-up R3 4K7 to +3.3V (no parasite power)
Power Supply
THIS works phenomenally well.
Encoder
Backlight (Rev D): anodes on +5V, Q1 low-side. R4-R7 430R = ~6.9 mA/LED @ Vf 2.0 V (assumed, LED P/N unknown); ~4.5 mA @ 3.0 V. Q1 Ic <= 30 mA, Ib ~2.4 mA (R14). R8 10K holds GPIO15 low at boot.
Enabling the chip: If you're using a bare-bone ESP-## board by AI Thinker, you have to add some resistors to turn on the ESP8266, and to select the right boot mode. 1.) Enable the chip by connecting the CH_PD (Chip Power Down, sometimes labeled CH_EN or chip enable) pin to VCC through a 10KΩ resist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

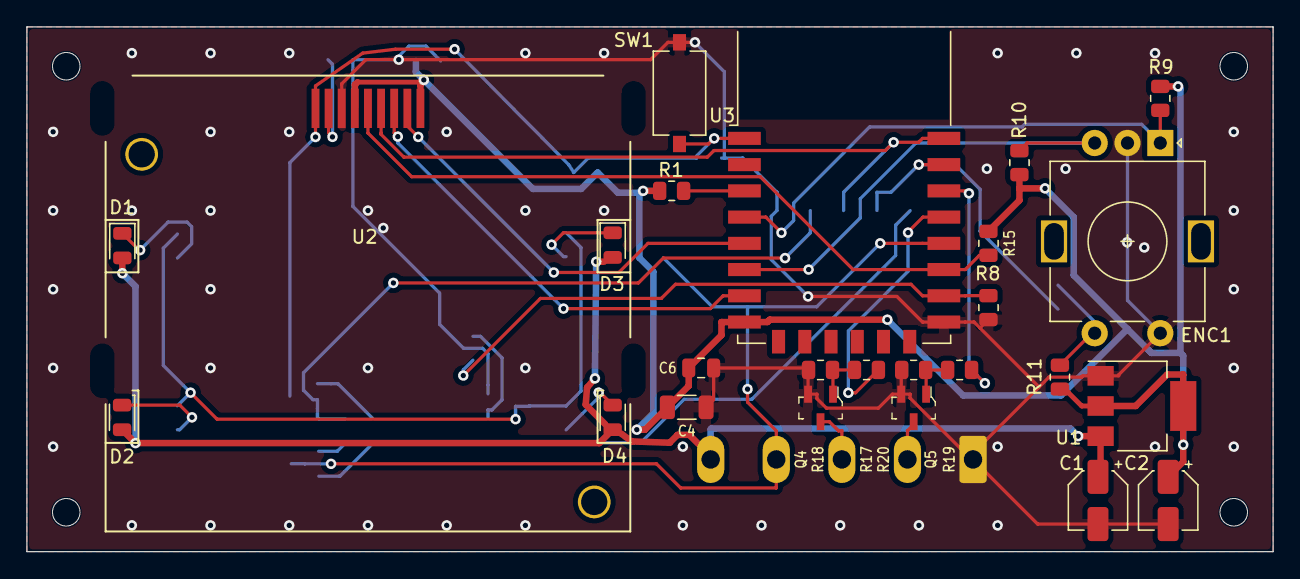
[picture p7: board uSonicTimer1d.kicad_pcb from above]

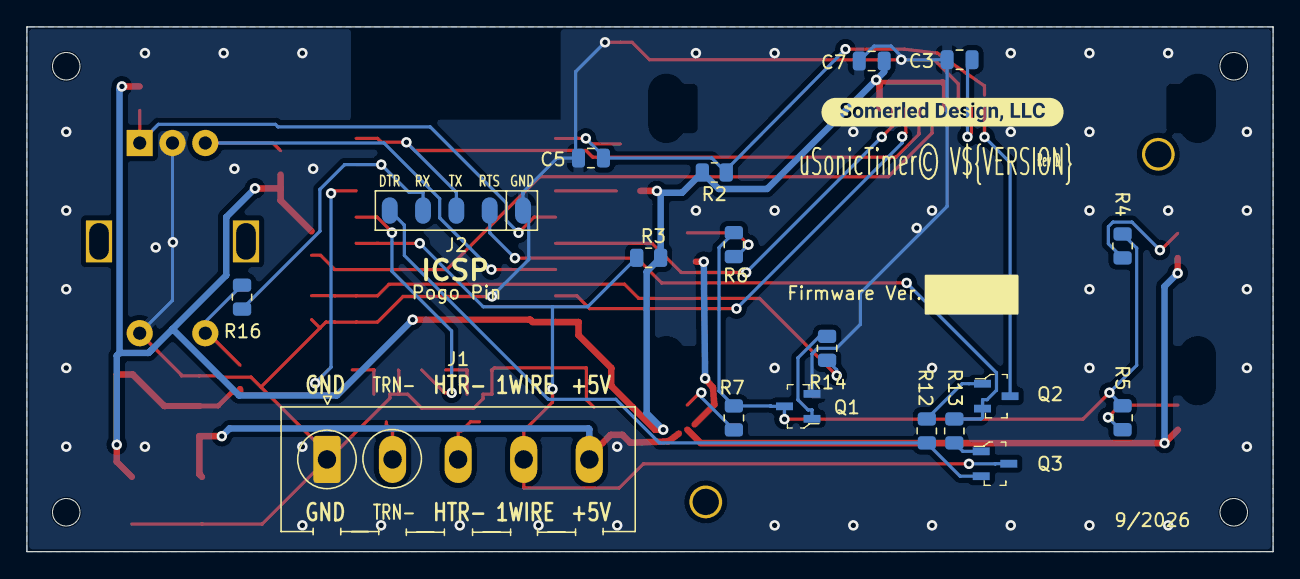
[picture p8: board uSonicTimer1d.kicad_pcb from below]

Board: 2 copper layers, 95.0 x 40.0 mm, 48 parts (19 on the bottom side), 32 nets.

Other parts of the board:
kibuzzard-63EC72D8: G***; kibuzzard-63EC72D8

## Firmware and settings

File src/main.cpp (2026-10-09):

/**
 * @file main.cpp
 * @remarks uSonicTimer
 * @author Kevin Murphy (https://www.SomerledDesign.com)
 * @brief an addition to an old, inexpensive Ultrasonic cleaner to include heating and timing
 * @version 0.6.1 (73)
 * @date 10/08/26
 *
 * @copyright Copyright (c) 2024 Somerled Design, LLC in Kevin Murphy
 *
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
 *
 *   This code is currently maintained for and compiled with Arduino 1.8.x.
 *   Your mileage may vary with other versions.
 *
 *   ATTENTION: LIBRARY FILES MUST BE PUT IN LIBRARIES DIRECTORIES AND NOT THE INO SKETCH DIRECTORY !!!!
 *
 *   FOR EXAMPLE:
 *   tiny4kOLED.h, tiny4kOLED.cpp ------------------------>   \Arduino\Sketchbook\libraries\tiny4kOLED\
 *
 *   Version History -
 *
 *   .100 - 01/16/22 - A work in progress
 *   .200 - 01/29/22 - rewrite with u8g2lib as display driver
 *   .300 - 08/20/24 - rewrite by GROK2.mini
 *   .400 - 08/28/24 - rewrite of Grok2 code by Kevin Murphy
 *   0.6.0 (72) - 10/08/26 - big-digit run screens (timer holds while heating), Settings menu,
 *                           F/C units, backlight 0 = off, contrast shown as 20-100
 *   0.6.1 (73) - 10/08/26 - blocky big-digit font; encoder acceleration in Set contrast;
 *                           a press saves in every settings page
 *
 * DISCLAIMER:
 *   With this design, including both the hardware & software I offer no guarantee that it is bug
 *   free or reliable. So, if you decide to build one and you have problems or issues and/or causes
 *   damage/harm to you, others or property then you are on your own. This work is experimental.
 *
 */
// Firmware version, shown as "0.6.1 (73)": semantic version MAJOR.MINOR.PATCH plus a build number.
// Bump PATCH for fixes, MINOR for features; 1.0.0 once it is installed and in service.
// FW_BUILD goes up by 1 for every build flashed for testing and never resets.
#define FW_VERSION "0.6.1"
#define FW_BUILD 73
#define HW_REV "D" // PCB rev 1d
/**
 *  Physical pins listed for comparison to pcb.
 *  in version 1b pcb 2/2023 the CS is connected to ground
 *  GPIO15 is used for
 *  PCB rev 1d (9/2026): LCD CS on GPIO2 (10K pull-up), backlight on GPIO15 (10K pull-down),
 *  1-Wire on GPIO0 (4K7 pull-up), encoder CLK on GPIO16. Heater/cleaner SSRs are now switched
 *  low-side by NPN transistors (GPIO HIGH = ON, same logic as before).
 *
 *
 *  === ESP8266 Pinout ===
 *  --- Power/Reset ---
 *                    Physical
 *                      PIN
 *   •   Vcc             8
 *   •   GND            15
 *   •   RST             1
 *
 *  --- Available  I/O ---
 *   •   GPIO0     D3   18
 *   •   GPIO1     D10  22  (TXD0) \
 *   •   GPIO3     D9   21  (RXD0)  |  If using as inputs don't call Serial.begin()
 *   •   GPIO2     D4   17  (TXD1)
 *
 *   •   GPIO4     D2   19  (SDA)   \
 *                                   }--> I2C
 *   •   GPIO5     D1   20  (SCL)   /
 *
 *   ◎   GPIO6     ☞    14  USED INTERNALLY - DO NOT USE **
 *   ◎   GPIO7     ☞    10  USED INTERNALLY - DO NOT USE **
 *   ◎   GPIO8     ☞    13  USED INTERNALLY - DO NOT USE **
 *   ◎   GPIO9     ☞    11  USED INTERNALLY - DO NOT USE **
 *   ◎   GPIO10    ☞    12  USED INTERNALLY - DO NOT USE **
 *   ◎   GPIO11    ☞     9  USED INTERNALLY - DO NOT USE **
 *
 *   •   GPIO14    D5    5  (SCLK) | \ S
 *   ●   GPIO12    D6    6  (MISO) |  |  P
 *   •   GPIO13    D7    7  (MOSI) |  |    I
 *   •   GPIO15    D8   16  (CS)   | /      ..
 *   •   GPIO16    D0    4  (no interrupt)
 *   •   ADC0      A0    2  (Analog Input)
 *
 * ----------------------------------------------------------------------------------------
 *  Required I/O (PCB rev 1d)
 *    SPI Nokia 5110
 *      Func          Non i/o     Digitial     GPIO i/o     ESP12e Pin         Descr.                   Ω out
 *     =========================================================================================================
 *    1 RESET          RST        RST          -           1                  RESET line
 *    2 CS                        D4           GPIO2       17                 CHIP SELECT (10K pull-up)
 *    3 D/C                       D10/TX       GPIO1       22                 DATA|COMMAND
 *    4 DIN                       D7(MOSI)     GPIO13      7                  MOSI
 *    5 CLK                       D5(SCLK)     GPIO14      5                  SCLK
 *    6 VCC            3V
 *    7 BL                        D8           GPIO15      16                 Backlight (via Q1, 10K pull-down)
 *    8 GND
 *
 *    Rotary Encoder
 *      Func          Non i/o     Digitial     GPIO i/o     ESP12e Pin        Descr.         Ω out
 *     ===========================================================================================
 *      ROT_ENC_A_PIN             D0           GPIO16      4                  CLK (4K7 pull-up, R9) ✓
 *      ROT_ENC_B_PIN             D6           GPIO12      6                  DT (4K7 pull-up, R10) ✓
 *      ROT_ENC_BUTTON_PIN        D9           GPIO3       21                 SW(/RX)           ✓
 *
 *    Relays
 *      Func          Non i/o     Digitial     GPIO i/o     ESP12e Pin         Descr.
 *     =====================================================================================
 *      HEATER_ENABLE_PIN         D2           GPIO4       19                 Heater relay
 *      DEVICE_ENABLE_PIN         D1           GPIO5       20                 Cleaner relay
 *
 *    Dallas Temp Sensor (DS18B20)
 *      Func          Non i/o     Digitial     GPIO i/o     ESP12e Pin         Descr.
 *     =====================================================================================
 *      ONE_WIRE_BUS              D3           GPIO0       18                  4K7 pull-up; also ~PROGRAM
 *
 *    ICSP Header (5 pin pogo pads)
 *      Func             Header pin    to -->                       ESP12e Pin    Ω out
 *     ===========================================================================================
 *     ICSP_GND_HDR_PIN      1        GND plane                       xx           ✓
 *     ICSP_RTS_HDR_PIN      2        Auto-Reset ckt.  (b Q3)         xx           ✓
 *     ICSP_TX_HDR_PIN       3        (this is tx in)                 22           ✓
 *     ICSP_RX_HDR_PIN       4        (this is _tx_ out)              21           ✓
 *     ICSP_DRT_HDR_PIN      5        Auto-Reset ckt.  (b Q2)         xx           ✓
 */
/**
 *
    Notes:
    This code assumes you have the necessary libraries installed. For ESPRotary and Button2, you might need to install them manually or via the Arduino IDE's library manager.
    The networkSettings() function is left unimplemented as it would require specific details about how you want to handle network connections.
    The saveSettings() and loadSettings() functions use EEPROM to persist settings across power cycles. Ensure you have enough EEPROM space on your ESP8266 module.
    The code uses a simple state machine for menu navigation, which should be expanded for more complex interactions or additional menu items.
    Error handling, especially for temperature sensor readings or network operations, should be added for robustness.
    Adjust the pin numbers according to your actual hardware setup.
 */

#include <OneWire.h>
#include <DallasTemperature.h>
// #include <ESPRotary.h> // replaced by the polled decoder in pollEncoder()
#include <Button2.h>
#include <U8g2lib.h>
#include <EEPROM.h>
#include "Ticker.h" // https://github.com/esp8266/Arduino/tree/master/libraries/Ticker
#include "ust_logic.h" // run control (hysteresis), units, contrast and progress helpers
#include "screens.h"   // page drawing (big-digit run screens, menus, settings pages)

#ifdef WITH_GDB
#include "GDBStub.h"
#endif

#if DEBUG
#define debugbegin(x) Serial.begin(x)
#define debug(x) Serial.print(x)
#define debugln(x) Serial.println(x)
#else
#define debugbegin(x)
#define debug(x)
#define debugln(x)
#endif // DEBUG

// Pin definitions (PCB rev 1d)
#define ONE_WIRE_BUS D3 // GPIO0 (4K7 pull-up, shared with ~PROGRAM)

#define CLEANER_PIN D1  // GPIO5
#define HEATER_PIN D2   // GPIO4

#define ROTARY_PIN1 D0     // GPIO16, CLK (polled; no interrupt on GPIO16)
#define ROTARY_PIN2 D6     // GPIO12, DT
#define ROTARY_BUTTON D9   // GPIO3, SW/RX

#define BACKLIGHT_PIN D8 // GPIO15 (10K pull-down, drives Q1)

#define LCD_SCLK_PIN D5   // GPIO14
#define LCD_DIN_PIN D7    // GPIO13
#define LCD_DC_PIN D10    // GPIO1 (TX)
#define LCD_CS_PIN D4      // GPIO2 (10K pull-up)
#define LCD_RST_PIN U8X8_PIN_NONE
// Status LED
// The backlight (PWM on GPIO15) is used as the status indicator, see updateBacklight():
// Steady       = normal operation (menu idle, cleaning) at the Set backlight level
// Flashing     = Heating up (1 Hz between the set brightness and ~30% of it)
// Pulsing      = timer finished, until any input (shows even if the backlight is toggled off)
// Double-blink = no temp sensor during a run, heater locked off (shows even if toggled off)
// Dim          = ~20% after 5 minutes idle in the menu; the first input only wakes it
// Heating/cleaning stay dark when the backlight has been toggled off or set to level 0.
// #define STATUS_LED_PIN ?   (not needed: the backlight is the status LED)
// bool statusLedOn = false;

// Encoder transitions per detent: 2 = half-cycle encoder (detents rest at both 00 and 11),
// 4 = full-cycle encoder (one rest state, e.g. always 11). A = B in every detent on the
// Rev D board; the encoder test screen (hold the button at power-up) shows which one it is.
#define ENCODER_STEPS_PER_DETENT 2

// Startup screen
#define FW_STR_(x) #x
#define FW_STR(x) FW_STR_(x)
#define STARTUP_LINE1 "uSonicTimer"
#define STARTUP_LINE2 "v" FW_VERSION " (" FW_STR(FW_BUILD) ")"
#define STARTUP_LINE3 "PCB Rev " HW_REV
#define STARTUP_SCREEN_MS 1500
// 84 px / 6 px font = 14 characters per line
static_assert(sizeof(STARTUP_LINE1) - 1 <= 14, "startup line 1 too long");
static_assert(sizeof(STARTUP_LINE2) - 1 <= 14, "startup line 2 too long");
static_assert(sizeof(STARTUP_LINE3) - 1 <= 14, "startup line 3 too long");
// -------------------------------------------------------------------------
//  NOKIA 5110 LCD
// #define sclk_pin D5
// #define dc_pin D6
// #define din_pin D7
// #define cs_pin D8
// #define rst_pin -1 // as in the Adafruit header...
//                       physically conn to RST switch
// -------------------------------------------------------------------------
// -------------------------------------------------------------------------

U8G2_PCD8544_84X48_F_4W_SW_SPI u8g2(
    U8G2_R0,        /* Rotation 0 = no rotation */
    LCD_SCLK_PIN,   /* clock */
    LCD_DIN_PIN,    /* data */
    LCD_CS_PIN,     /* cs */
    LCD_DC_PIN,     /* dc */
    LCD_RST_PIN     /* reset */
);

// Temp Sensor Data Bus
OneWire oneWire(ONE_WIRE_BUS);
DallasTemperature sensors(&oneWire);

// TODO: is this the correct address?
//  address of thermometer on oneWire bus
//  are they different for each DS18B20?
//                                  0x28, 0xFF, 0x57, 0x3F, 0x01, 0x16, 0x01, 0xED
DeviceAddress thermometerAddress; // custom array type to hold 64 bit device address

// Rotary Encoder and button
Ticker t;
Button2 b;

// Variables
float currentTemperature = 0;
uint8_t g_setTemperatureF;   // The set temperature in Fahrenheit
uint8_t g_timerSetting;      // The timer to be set in minutes
uint8_t g_contrast;          // The contrast for the display (raw U8g2 value 80..200)
bool g_unitsC = false;       // display unit: false = F, true = C (control logic is always F)
uint16_t longPress = 1000;   // one second long press of button
bool g_backlightOn = true;   // backlight state; toggled by a short press in the menus
uint8_t g_backlightLevel;    // backlight brightness level 0..10 (0 = off; Set backlight page)
uint8_t g_previewLevel = 0;  // level previewed while the Set backlight page is open
bool g_previewActive = false; // true while the Set backlight page previews g_previewLevel

// EEPROM layout (one byte per setting; addresses kept from earlier firmware so saved
// temperature/timer/contrast/backlight values survive the update)
#define EEPROM_SIZE           512
#define EEPROM_ADDR_SET_TEMP  0x00 // uint8_t g_setTemperatureF
#define EEPROM_ADDR_TIMER     0x08 // uint8_t g_timerSetting
#define EEPROM_ADDR_CONTRAST  0x10 // uint8_t g_contrast, raw 80..200 (shown as 20..100)
#define EEPROM_ADDR_BACKLIGHT 0x18 // uint8_t g_backlightLevel
#define EEPROM_ADDR_UNITS     0x20 // uint8_t UNITS_F / UNITS_C (new in 0.6.0)
#define EEPROM_ADDR_LAYOUT    0x28 // uint8_t EEPROM_LAYOUT_ID, written by 0.6.0 and later
#define EEPROM_LAYOUT_ID      0x60 // marks a layout that knows backlight level 0 and the units byte
#define UNITS_F               0
#define UNITS_C               1
static_assert(EEPROM_ADDR_SET_TEMP + sizeof(uint8_t) <= EEPROM_ADDR_TIMER, "EEPROM: set temp overlaps timer");
static_assert(EEPROM_ADDR_TIMER + sizeof(uint8_t) <= EEPROM_ADDR_CONTRAST, "EEPROM: timer overlaps contrast");
static_assert(EEPROM_ADDR_CONTRAST + sizeof(uint8_t) <= EEPROM_ADDR_BACKLIGHT, "EEPROM: contrast overlaps backlight");
static_assert(EEPROM_ADDR_BACKLIGHT + sizeof(uint8_t) <= EEPROM_ADDR_UNITS, "EEPROM: backlight overlaps units");
static_assert(EEPROM_ADDR_UNITS + sizeof(uint8_t) <= EEPROM_ADDR_LAYOUT, "EEPROM: units overlaps layout id");
static_assert(EEPROM_ADDR_LAYOUT + sizeof(uint8_t) <= EEPROM_SIZE, "EEPROM: layout id outside EEPROM");
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
void loop()
{

    debugln("Entering loop()...");

    handleLoop(); // poll the encoder/button every pass, not only from the 10ms Ticker
    updateBacklight();

    displayMenu();

    // debug("displayMenu complete...");

    readRotaryEncoder();
    const ButtonEvent event = readButton();

    // debug("rotaryEncoder has been read...");

    // idle dim: the first input after dimming only wakes the backlight
    if (g_dimmed)
    {
        if (down || up || event != BUTTON_NONE)
        {
            down = false;
            up = false;
            last = g_encPosition; // drop any further detents of the waking turn
            g_dimmed = false;
            updateBacklight(true);
        }
        return;
    }
    if (backlightLit() && g_blStatus == BL_IDLE && (millis() - g_lastActivityMs) >= IDLE_DIM_MS)
    {
        g_dimmed = true;
    }

    // handle encoder events: move the highlight in the current menu (wraps around)
    ////////////////////////////////////////////
    const bool inSettings = (g_menuLevel == MENU_SETTINGS);
    const uint8_t count = inSettings ? static_cast<uint8_t>(SETTINGS_ITEMS_COUNT) : static_cast<uint8_t>(MAIN_ITEMS_COUNT);
    uint8_t &selected = inSettings ? g_settingsItem : g_currentMenu;
    if (down)
    {
        debug("down rotate...");
        down = false;
        selected = (selected + 1) % count;
    }
    if (up)
    {
        debug("up rotate...");
        up = false;
        selected = (selected + count - 1) % count;
    }

    // handle button events: long press opens the highlighted item
    ////////////////////////////////////////////
    if (event == BUTTON_LONG)
    {
        if (!inSettings)
        {
            switch (g_currentMenu)
            {
            case MAIN_START:
                debug("long press on Start...");
                startTimerPage();
                break;
            case MAIN_SETTINGS:
                g_menuLevel = MENU_SETTINGS;
                g_settingsItem = SETTINGS_TEMP;
                break;
            default:
                break;
            }
        }
        else
        {
            switch (g_settingsItem)
            {
            case SETTINGS_TEMP:
                setTemperatureSubmenu();
                break;
            case SETTINGS_TIME:
                setTimerSubmenu();
                break;
            case SETTINGS_UNITS:
                setUnitsSubmenu();
                break;
            case SETTINGS_BACKLIGHT:
                setBacklightSubmenu();
                break;
            case SETTINGS_CONTRAST:
                adjustContrast();
                break;
            default: // SETTINGS_EXIT
                g_menuLevel = MENU_MAIN;
                break;
            }
        }
        debugln("Loop complete.");
    }
    else if (event == BUTTON_SHORT)
    {
        // short press in the menus toggles the backlight;
        // pages use short presses for their own purposes and leave it alone
        toggleBacklight();
    }
}

/**
 * @brief Runs the cleaner: heats first, then counts down while cleaning.
 *
 * Called when the user selects "Start". The countdown holds while the heater is on and only
 * runs while the water is within 10 F of the set temperature (cleaner on), see nextRunState():
 *   heating  -> heater on, cleaner off, countdown held; big current temperature on screen
 *   cleaning -> heater off, cleaner on, counting down; big MM:SS on screen
 *   The heater comes on below (set - 10 F) and cleaning resumes at (set - 8 F).
 *   no sensor -> fail-safe: heater off, cleaner on, counting down; "NO SENSOR" under the time
 * A long press aborts. When the time is up both outputs go off and the DONE screen stays
 * until any input.
 */
void startTimerPage()
{
    const uint32_t totalMs = static_cast<uint32_t>(g_timerSetting) * 60UL * 1000UL;
    uint32_t elapsedMs = 0;   // run time; only advances while cleaning (or without a sensor)
    bool finished = false;
    RunState state = RUN_START;
    float heatStartF = 0.0f;  // temperature when the heater (re)engaged, for the progress rule
    char line[24];

    // one blocking read so the first heater decision uses a fresh temperature, then non-blocking
    // conversions so the page (encoder, button, backlight status) keeps running during the 750ms
    sensors.requestTemperatures();
    currentTemperature = sensors.getTempFByIndex(0);
    sensors.setWaitForConversion(false);
    sensors.requestTemperatures();
    unsigned long lastRequest = millis();
    unsigned long lastTick = millis();

    while (true)
    {
        servicePage();
        const unsigned long now = millis();
        // the time since the last pass counts only if that pass was cleaning (or had no sensor)
        if (runStateCounts(state))
        {
            elapsedMs += now - lastTick;
        }
        lastTick = now;

        if (elapsedMs >= totalMs)
        {
            finished = true;
            break;
        }

        if (now - lastRequest >= TEMP_CONVERSION_MS)
        {
            currentTemperature = sensors.getTempFByIndex(0);
            sensors.requestTemperatures();
            lastRequest = millis();
        }
        // no sensor (DEVICE_DISCONNECTED_F = -196.6F) must never leave the heater on
        const bool sensorOk = currentTemperature > (DEVICE_DISCONNECTED_F + 1.0f);

        const RunState next = nextRunState(state, sensorOk, currentTemperature, g_setTemperatureF);
        if (next == RUN_HEATING && state != RUN_HEATING)
        {
            heatStartF = currentTemperature; // progress rule starts from here
        }
        state = next;

        // switch the output that goes off first, so heater and cleaner are never on together
        switch (state)
        {
        case RUN_HEATING:
            turnOffCleaner();
            turnOnHeater();
            g_blStatus = BL_HEATING;
            break;
        case RUN_NO_SENSOR:
            // fail-safe: heater off, cleaner still runs for the timer (cleaning without temp control)
            turnOffHeater();
            turnOnCleaner();
            g_blStatus = BL_FAULT;
            break;
        default: // RUN_CLEANING
            turnOffHeater();
            turnOnCleaner();
            g_blStatus = BL_CLEANING;
            break;
        }

        const int16_t setShown = displayTemp(g_setTemperatureF, g_unitsC);
        if (state == RUN_HEATING)
        {
            snprintf(line, sizeof(line), "Heating to %d%s", setShown, unitSuffix());
            drawHeatingScreen(u8g2, displayTemp(currentTemperature, g_unitsC), g_unitsC,
                              heatProgressPx(heatStartF, currentTemperature, g_setTemperatureF, LCD_WIDTH), line);
        }
        else
        {
            formatTimerLine(u8g2, line, sizeof(line), sensorOk, displayTemp(currentTemperature, g_unitsC), setShown, g_unitsC);
            // colon blinks at 1 Hz with the counted time
            drawTimerScreen(u8g2, remainingSeconds(totalMs, elapsedMs), (elapsedMs % 1000UL) < 500UL,
                            progressPx(static_cast<int32_t>(elapsedMs), static_cast<int32_t>(totalMs), LCD_WIDTH), line);
        }
        sendBufferPolled();

        // long press aborts the timer
        if (readButton() == BUTTON_LONG)
        {
            break;
        }
    }
    sensors.setWaitForConversion(true);
    turnOffCleaner();
    turnOffHeater();
    g_blStatus = finished ? BL_DONE : BL_IDLE; // pulse until any input when the timer ran out
    g_lastActivityMs = millis();
    last = g_encPosition; // ignore any turning done while the timer page was shown
    down = false;
    up = false;
    if (finished)
    {
        showDonePage();
    }
}

/**
 * @brief Big "DONE" screen after a completed run; any turn or press returns to the menu.
 *
 * The backlight keeps pulsing (BL_DONE) until that input, see noteActivity().
 */
void showDonePage()
{
    char line[20];
    snprintf(line, sizeof(line), "Cleaned %u min", static_cast<unsigned>(g_timerSetting));
    drawDoneScreen(u8g2, line);
    sendBufferPolled();
    while (true)
    {
        servicePage();
        readRotaryEncoder();
        const ButtonEvent event = readButton();
        if (down || up || event != BUTTON_NONE)
        {
            break;
        }
    }
    down = false;
    up = false;
    last = g_encPosition;
}
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

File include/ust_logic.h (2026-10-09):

/**
 * @file ust_logic.h
 * @brief Run control, unit conversion and scaling helpers for uSonicTimer.
 *
 * Plain C++ without Arduino dependencies so the same code can be tested on a PC
 * (see tools/host/). All temperatures are degrees Fahrenheit unless the name says C.
 */
#pragma once

#include <stdint.h>
#include <math.h>

// ---- settings ranges -------------------------------------------------------
#define SET_TEMP_MIN_F    60
#define SET_TEMP_MAX_F    180
#define SET_TEMP_MIN_C    16  // 60 F = 15.6 C, rounded up so it stays inside the F range
#define SET_TEMP_MAX_C    82  // 180 F = 82.2 C, rounded down
#define CONTRAST_MIN      80  // raw U8g2 contrast; U8g2 sends contrast >> 1 as the PCD8544 Vop
#define CONTRAST_MAX      200 // outside 80..200 the display blanks
#define CONTRAST_DEFAULT  128 // = Vop 0x40, the U8g2 init value
#define CONTRAST_UI_MIN   20  // shown in the Set contrast page, mapped linearly onto 80..200
#define CONTRAST_UI_MAX   100

// ---- run control -------------------------------------------------------------
// The heater comes on below (set - 10 F). The cleaner and the countdown resume at (set - 8 F),
// so there is a 2 F gap between heating and cleaning. The heater is off while cleaning.
#define HEAT_ON_OFFSET_F  10.0f
#define RESUME_OFFSET_F   8.0f

enum RunState : uint8_t
{
    RUN_START,    // nothing decided yet (first pass)
    RUN_HEATING,  // heater on, cleaner off, countdown held
    RUN_CLEANING, // heater off, cleaner on, counting down
    RUN_NO_SENSOR // fail-safe: heater off, cleaner on, counting down without temperature control
};

/**
 * @brief Next run state from the current one and a temperature reading (hysteresis).
 * @param sensorOk false when the DS18B20 is missing/disconnected
 */
inline RunState nextRunState(RunState state, bool sensorOk, float tempF, float setF)
{
    if (!sensorOk)
    {
        return RUN_NO_SENSOR;
    }
    const float heatBelow = setF - HEAT_ON_OFFSET_F;
    const float resumeAt = setF - RESUME_OFFSET_F;
    switch (state)
    {
    case RUN_HEATING:
        return (tempF >= resumeAt) ? RUN_CLEANING : RUN_HEATING;
    case RUN_CLEANING:
        return (tempF < heatBelow) ? RUN_HEATING : RUN_CLEANING;
    default: // RUN_START, or the sensor just came back: decide like the old firmware did
        return (tempF < heatBelow) ? RUN_HEATING : RUN_CLEANING;
    }
}

/// true when the countdown (and the elapsed run time) advances in this state
inline bool runStateCounts(RunState state)
{
    return state == RUN_CLEANING || state == RUN_NO_SENSOR;
}

/// whole seconds still to run, rounded up (shows 10:00 for the first second of a 10 min run)
inline uint16_t remainingSeconds(uint32_t totalMs, uint32_t elapsedMs)
{
    if (elapsedMs >= totalMs)
    {
        return 0;
    }
    return static_cast<uint16_t>((totalMs - elapsedMs + 999UL) / 1000UL);
}

// ---- encoder acceleration (value editors only, not menu navigation) -----------
// The gap is the time between two detents turned in the same direction. A quick turn crosses
// the 80 contrast steps (about 1 + 16 x 5 detents); single clicks are far slower than 90 ms.
#define ENC_ACCEL_FAST_MS      40 // detents closer than this count as ENC_ACCEL_FAST_STEPS
#define ENC_ACCEL_MEDIUM_MS    90 // closer than this count as ENC_ACCEL_MEDIUM_STEPS
#define ENC_ACCEL_FAST_STEPS   5
#define ENC_ACCEL_MEDIUM_STEPS 2
#define ENC_GAP_NONE           0xFFFF // first detent, or the direction changed

inline uint8_t encoderAccelSteps(uint16_t gapMs)
{
    if (gapMs < ENC_ACCEL_FAST_MS)
    {
        return ENC_ACCEL_FAST_STEPS;
    }
    if (gapMs < ENC_ACCEL_MEDIUM_MS)
    {
        return ENC_ACCEL_MEDIUM_STEPS;
    }
    return 1;
}

// ---- rounding and units ------------------------------------------------------
inline int16_t roundToInt(float v)
{
    if (v > 32000.0f)
    {
        return 32000;
    }
    if (v < -32000.0f)
    {
        return -32000;
    }
    return static_cast<int16_t>(floorf(v + 0.5f));
}

inline float fToC(float f) { return (f - 32.0f) * 5.0f / 9.0f; }
inline float cToF(float c) { return c * 9.0f / 5.0f + 32.0f; }

/// whole degrees in the display unit, clamped to -99..999 so it always fits the big font
inline int16_t displayTemp(float tempF, bool celsius)
{
    const int16_t v = roundToInt(celsius ? fToC(tempF) : tempF);
    return (v < -99) ? -99 : (v > 999) ? 999 : v;
}

/// a set temperature entered in C, stored as whole F within SET_TEMP_MIN_F..SET_TEMP_MAX_F
inline uint8_t setTempFromC(int16_t c)
{
    if (c < SET_TEMP_MIN_C)
    {
        c = SET_TEMP_MIN_C;
    }
    if (c > SET_TEMP_MAX_C)
    {
        c = SET_TEMP_MAX_C;
    }
    int16_t f = roundToInt(cToF(c));
    f = (f < SET_TEMP_MIN_F) ? SET_TEMP_MIN_F : (f > SET_TEMP_MAX_F) ? SET_TEMP_MAX_F : f;
    return static_cast<uint8_t>(f);
}

// ---- contrast ----------------------------------------------------------------
/// raw 80..200 -> shown 20..100 (rounded)
inline uint8_t contrastRawToUi(uint8_t raw)
{
    if (raw < CONTRAST_MIN)
    {
        raw = CONTRAST_MIN;
    }
    if (raw > CONTRAST_MAX)
    {
        raw = CONTRAST_MAX;
    }
    const uint16_t uiSpan = CONTRAST_UI_MAX - CONTRAST_UI_MIN;
    const uint16_t rawSpan = CONTRAST_MAX - CONTRAST_MIN;
    return static_cast<uint8_t>(CONTRAST_UI_MIN + ((raw - CONTRAST_MIN) * uiSpan + rawSpan / 2) / rawSpan);
}

/// shown 20..100 -> raw 80..200 (rounded)
inline uint8_t contrastUiToRaw(uint8_t ui)
{
    if (ui < CONTRAST_UI_MIN)
    {
        ui = CONTRAST_UI_MIN;
    }
    if (ui > CONTRAST_UI_MAX)
    {
        ui = CONTRAST_UI_MAX;
    }
    const uint16_t uiSpan = CONTRAST_UI_MAX - CONTRAST_UI_MIN;
    const uint16_t rawSpan = CONTRAST_MAX - CONTRAST_MIN;
    return static_cast<uint8_t>(CONTRAST_MIN + ((ui - CONTRAST_UI_MIN) * rawSpan + uiSpan / 2) / uiSpan);
}

// ---- progress bars -------------------------------------------------------------
/// num/den of width pixels, clamped to 0..width (den <= 0 counts as complete)
inline uint8_t progressPx(int32_t num, int32_t den, uint8_t width)
{
    if (den <= 0 || num >= den)
    {
        return width;
    }
    if (num <= 0)
    {
        return 0;
    }
    return static_cast<uint8_t>((static_cast<int64_t>(num) * width) / den);
}

/// heating progress from the temperature the heater came on at to the resume threshold (set - 8 F)
inline uint8_t heatProgressPx(float startF, float nowF, float setF, uint8_t width)
{
    const float target = setF - RESUME_OFFSET_F;
    const float span = target - startF;
    if (span < 0.1f)
    {
        return (nowF >= target) ? width : 0;
    }
    float frac = (nowF - startF) / span;
    if (!(frac > 0.0f)) // also catches NaN
    {
        return 0;
    }
    if (frac >= 1.0f)
    {
        return width;
    }
    return static_cast<uint8_t>(frac * width);
}

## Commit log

2024-10-01 added RoughTime.h and cleaned up Grok code
    [zones.csv]
2026-09-30 PCB rev 1d pin map: LCD CS GPIO2, backlight GPIO15 via Q1, encoder CLK GPIO16, 1-Wire GPIO0
2026-09-30 Fix contrast EEPROM address and backlight toggle; remove stale files
    [zones.csv]
2026-10-04 License firmware GPL-3.0-or-later and hardware CERN-OHL-S-2.0
    Add LICENSE (full GPL-3.0 text) for the firmware and code, and
    LICENSE-HARDWARE (CERN-OHL-S v2) for the KiCad hardware design files, and
    explain the split in the README.
2026-10-04 Add KiCad design files for the rev 1d controller board
    hardware/uSonicTimer_1d/: KiCad 10 project, schematic, PCB, design rules,
    project symbol and footprint libraries with ${KIPRJMOD} lib tables,
    Gerber/drill outputs (plus the rev D order zip), interactive BOM, renders
    and next-revision notes. Backups, autosaves, locks, fp-info-cache and the
    per-user .kicad_prl are excluded via hardware/.gitignore.
    README: point the pin map and repository layout at hardware/, and state
    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
    [uSonicTimer1d-B_Cu.gbl, uSonicTimer1d-B_Mask.gbs, uSonicTimer1d-B_Paste.gbp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]
2026-10-05 hardware/uSonicTimer_1d: self-contained project libs + 3D models
    Every symbol and footprint was already in the project libraries
    (nickname uSonicTimer1d, ${KIPRJMOD} tables). This commit removes the
    remaining 3D-model references outside the project and the stock KiCad
    library. The board's embedded footprints and uSonicTimer1d.pretty now
    use the same model list.
    - Q1-Q5 (SOT-23-3): swap the absolute-path km3dpacks "User Library-SOT23-3"
    STEP (provenance unclear) for the stock SOT-23-3.step.
    - SW1 (PTS636): drop the ${MYSPECLMOD} GrabCAD STEP (file missing and
    not redistributable); show the stock KiCad model, which was already hidden
    on the footprint.
    - ENC1 (EC11E): drop the ${MYSPECLM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
    [uSonicTimer1d.kicad_pcb]
2026-10-05 hardware/uSonicTimer_1d: add own coloured 3D models for ENC1, J1 and U2
    Drawn by Somerled Design (Kevin Murphy) with Mildrew (Grok Bot), CERN-OHL-S-2.0.
    Multi-colour STEP + VRML generated by 3dmodels/build_3dmodels.py (CadQuery),
    dimensions from the datasheets listed in 3dmodels/README.md:
    - ENC1: Alps EC11E with switch, vertical, 20 mm shaft
    - J1: Metaltex BR4 5.0 mm terminal block, 5 ways (BR402V + BR403V)
    - U2: bare Nokia 5110/3310 LCD in metal frame (Goldentek GG0804A1FSN6G
    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
    [LCD_Nokia_5110-3310_bare_frame.step, RotaryEncoder_Alps_EC11E_Switch_Vertical_H20mm.step, TerminalBlock_Metaltex_BR4_1x05_P5.00mm_Horizontal.step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]
2026-10-08 Fix watchdog resets in page loops, Set Temp drawing, EEPROM defaults, no-sensor heater fail-safe, 5110 text fit
    - servicePage(): handleLoop() + yield() in every blocking page loop (soft WDT reset after ~3 s); never called from the Ticker
    - Set Temp: cursor box on the digit line, draw colour always restored; setFontMode(1); +2 glyph centring (Set Temp, Contrast)
    - loadSettings: range-check temp/timer/contrast (erased flash = 0xFF); contrast default 128; clamp contrast 80-200 and set temp 60-180 on save
    - Timer page: no DS18B20 -> heater off, cleaner runs for the timer, shows "Temp: --"
    - 14-char layouts: Set Timer value on line 2; timer page Time Left / MM:SS / Now / Set
    - platformio.ini: def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
    [main.cpp]
2026-10-08 Poll encoder during LCD redraws so detents are not missed
    - sendBufferPolled(): send the frame in 18 4x1-tile pieces with handleLoop() between them (full SW-SPI sendBuffer blocks ~14 ms and the Ticker cannot run during it)
    - loop(): call handleLoop() every pass, not only from the 10 ms Ticker
    - readRotaryEncoder(): consume one detent per call; resync after the timer page
    - GPIO16 (encoder A): explicit pinMode INPUT after r.begin (no internal pull-up; INPUT_PULLUP leaves GP16E untouched)
    [main.cpp]
2026-10-08 Backlight as status indicator and Backlight brightness menu
    - PWM backlight (analogWrite, 1 kHz) at a saved level 1-10 (EEPROM 0x18, default 10); short press toggles off/level
    - Status: steady = idle/cleaning, 1 Hz flash = heating, slow pulse = timer finished (until input), double-blink = no sensor; finished/fault override a toggled-off backlight
    - Idle dim to ~20% after 5 min in the menu; first input only wakes
    - Backlight page with bar graph and live preview; long press saves
    - Main menu scrolls (4 visible rows); Contrast clockwise = increase
    - Timer page uses non-blocking DS18B20 conversions so status effects and inputs keep running
    - README and status comment updated
    [main.cpp]
2026-10-08 Replace ESPRotary with a polled quadrature decoder (2 steps per detent), add encoder test screen; build 70
    [main.cpp]
2026-10-08 Use ck upload reset method for no-DTR FTDI cable
2026-10-08 Timer screen label "Time:"; note pogo-pin upload in platformio.ini
2026-10-08 v0.6.0 (72): big-digit run screens, countdown holds while heating, Settings menu, F/C units
    Run control
    - The countdown holds while heating and only runs while cleaning (or without a sensor);
    elapsed run time only accumulates then.
    - Hysteresis: heater on below set - 10 F, cleaner and countdown resume at set - 8 F.
    Temperatures stay float (tenths) internally; screens show whole degrees.
    - No sensor: unchanged fail-safe (heater off, cleaner on, counting), shown as "NO SENSOR".
    - Long press still aborts. When the time is up a big DONE screen stays until any input
    (the backlight keeps its done pulse until then).
    Screens (src/screens.cpp, include/screens.h, include/bigfont.h)
    - Big charac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
    [main.cpp, ust_logic.h]
2026-10-09 v0.6.1 (73): blocky big-digit font, encoder acceleration, Press = save
    - Big digits: new squared-off, 7-segment-style font modelled on the cbm80amiga Nokia 5110
    clock (include/bigfont.h, box lists drawn with drawBox): 15x28 cells, 4 px horizontal bars,
    4 px upper / 5 px lower verticals (stepped silhouette), no diagonals except a stepped slash
    in the zero, colon of two 4x4 blocks, minus and D O N E. Replaces the scaled 5x7 glyphs;
    layout and positions unchanged ("00:23" is now 76 px wide).
    - Encoder acceleration in Set contrast only: detents < 40 ms apart count 5 steps, < 90 ms
    count 2, slower 1 (the first detent and a change of direction always count 1). Timing is
    taken in pollEn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
    [main.cpp, test_logic.cpp, ust_logic.h]
2026-10-09 docs: README status and encoder pull-up comment (4K7, R9/R10)

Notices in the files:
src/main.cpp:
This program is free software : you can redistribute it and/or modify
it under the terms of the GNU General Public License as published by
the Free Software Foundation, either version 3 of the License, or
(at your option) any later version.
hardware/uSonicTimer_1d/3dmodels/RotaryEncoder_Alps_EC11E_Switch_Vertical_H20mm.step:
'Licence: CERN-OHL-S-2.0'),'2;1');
